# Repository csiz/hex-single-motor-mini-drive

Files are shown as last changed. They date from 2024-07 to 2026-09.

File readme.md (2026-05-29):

Hex Mini FOC driver
===================

Brushless motor driver for mini gear motors and servos. This driver focuses on fine force control
using field oriented control (FOC). The motor can be commanded to move to track position, 
velocity, and/or force. The driver will maintain the current wave exactly 90 degrees out
of phase to the EMF wave for maximum efficieny. Position is tracked via hall sensors, EMF
feedback and I2C rotary sensors.

Electrical ranges: 
- Maximum motor voltage: 28V
- Maximum current: 5A
- Minimum motor voltage: 6V
- Nominal I2C voltage: 3.3V

This project has 4 main components, for details look at the `readme.md` files in each directory:
* A brushless motor simulator and motor principles explainer; under `motor-sim`.
* The driver PCB schematic and manufacturing files; under `circuits`.
* Custom driver firmware with Kalman filter position tracking and FOC driving logic; under `driver-code`.
* Driver control and monitoring webapp; also under `motor-sim`, the page titled `motor-monitor.md`.

(TODO: this section needs updating to include the master circuit and master code and versioning and media and circuit libraries layout)

Screenshots
-----------

Motor monitor should look like this when connected to a motor: motor monitor screenshot

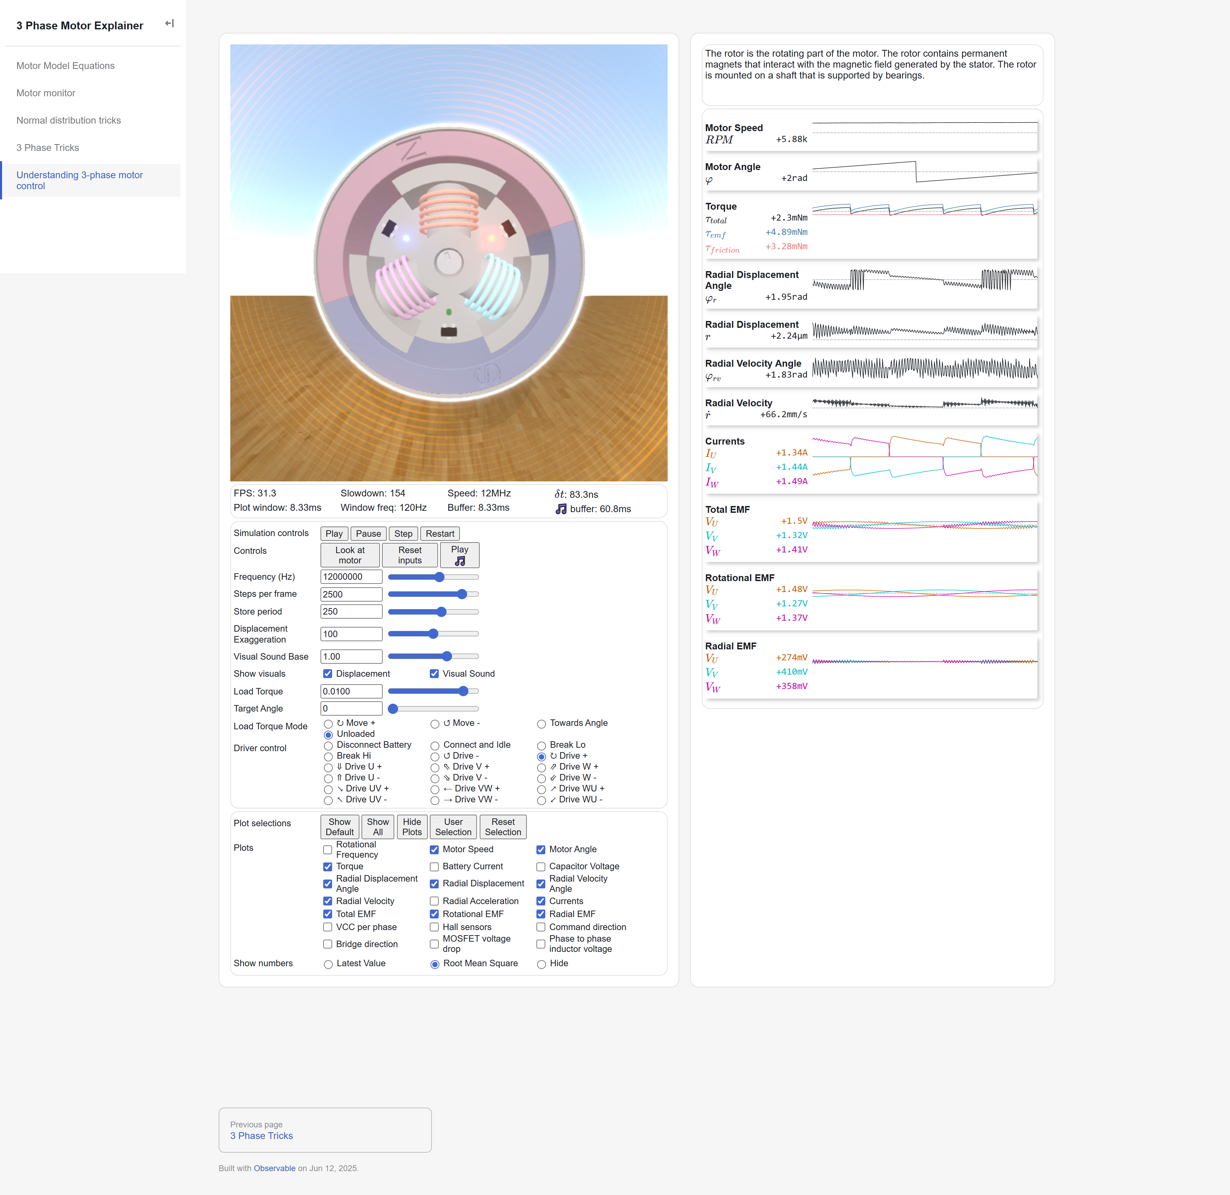
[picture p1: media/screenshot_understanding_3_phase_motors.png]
motor sim screenshot
The motor sim, with GPU rendered soundwaves should look like this: 

Circuit Dev Log
---------------

Lessons learnt for driver code v0.4
-----------------------------------

[ ] VREF must be independent of the reference to the amplifier; and actually well insulated. The v0.2 and v0.3 are too noisy because of this I suspect.
[ ] Let's go back to USB with 5V and separate VCC power connector! Also allows us to drop the on-board buck converter and save space. Bonus for easy to
control from a computer/phone with any USB cable.

Tasks for v0.3
--------------

[v] Maybe switch to a oscillation damping gate resistor of 3ohm. The AO4266E switching parameter uses 
Rgen = 3ohm, I think this is their recommended gate resistance. Switched to 4.7ohm, closest basic resistor.

[v] Aaaargh!!! BOOT0 pin needs a pulldown resistor on the STM32G4!
[x] VREF+ should be tied to VDDA... VREF+ now has the capacitance required and drives the amplifier refrence too.

[v] Think about connectors better. We should either drop or double down on USB-C. It would be very user friendly and the power delivery 
allows us to pick the 9-24V we need, but might be cumbersombe to control 24 devices. The SPI bus with slim connectors let's us keep it 
tight and in-house. Would we want a cheap single-sided board with USB-C and also a compact double sided assembly without USB at all.
... Let's go for double sided compact without USB, with the better stm32g4 with 5 opamps (so we can also ditch the opamp).
[v] USB-C footprint was correct with the cutouts. What we have now is incorrect!

[v] Need master circuit.
[v] Need flexi rotation I2C sensors.
[v] Via diameter was too small, should be at least 0.2/0.45

Need to implement in v0.2
-------------------------

Features of current version:
[v] Measure power line voltage.
[x] Re-pick voltage boost capacitor and resistor pair (using P FETS).
[v] Re-pick gate oscillation damping resistor for the inputs to the power MOSFET.
[v] Crystal oscilator and pick matching caps.
[v] Power regulator.
[v] USB-C connector maybe?
[v] Debugging connection with the trace line.
[v] 4 half bridge outputs
[v] 4 voltage inputs for the 4 outputs
[v] 1 voltage input for VCC
[v] 2 (preferably 4) current inputs from the 4 outputs; I chose 4.
[x] maybe 1 current input for total current. It would leave us with a floating ground which is iffy.
[v] SPI connection to main board. Not ~I2C~, it's too slow and consumes too much current. SPI will need
a chip select pin, but allows for parallel devices. SPI has hardware CRC calculation, seems useful.
[v] Spare I2C connection for the magnetic sensors.
[v] Status LED.

Lessons from previous version:
[x] Measure gate turn on characteristics of existing circuit...
[x] Maybe switch to a oscillation damping gate resistor of 3ohm. The AO4266E switching parameter uses 
Rgen = 3ohm, I think this is their recommended gate resistance.
[x] Definitely need to think about daisy chaining these, maybe use a signal buffer/transciever with an enable pin,
and/or mosfet switch for the chip power on. I2C to master board is probably the best and easiest way.
[v] Oopsies I flipped the sign of the V phase current measurement lines.
[x] The boost gate should maybe be connected to the driver side of the shunt resistor. At the moment we're measuring current used to charge the high gate.
[x] There's a summing option for the current measurments. Try outputing U, V, U+V, U+V+W using the 4th spare output.
[v] ! Think carefully about the shunt resistor placement, there's big interference going on if we measure during high side. Timing it around ground as
common mode voltage seems to fix it. Is that the only way to measure all current going through the motor coils?
[v] ! Measure voltage of the motor coils!
[x] There's a conflict between i2c and timer 3 channel 2. Choose a different GPIO for the red LED.
	I2C1 and TIM3_CH2 remapped
	Description
	When the following conditions are met:
	• I2C1 and TIM3 are clocked.
	• I/O port pin PB5 is configured as an alternate function output
	there is a conflict between the TIM3_CH2 signal and the I2C1 SMBA signal (even if SMBA is not used).
	In these cases the I/O port pin PB5 is set to 1 by default if the I/O alternate function output is selected and I2C1 is
	clocked. TIM3_CH2 cannot be used in output mode.
	Workaround
	To avoid this conflict, TIM3_CH2 can only be used in input mode.

[x] Double sided board. Not just yet.
[x] Drop voltage regulator and rely on master board for 3.3V; filter it though. We just needed to look for better 
components, there are cheap and small options that work well for us.
[x] Look for thinner IDC connector, and definitely SMD version for easier routing, use of space behind connector.
[v] Add voltage probes for the phase connectors so we can measure voltage both during driving and open connections.
We need to measure driving voltage to make sure our MOSFETS are turned on and giving us the voltage we command!
[v] Use Kelvin sense resistors (or pad hack) for the current measurement to avoid the unknown solder resistance.
https://www.analog.com/media/en/analog-dialogue/volume-46/number-2/articles/optimize-high-current-sensing-accuracy.pdf
[v] Don't drop the hall sensors, yet!
[v] The big problem with our measurements occurs when we switch from continuous 0 output from the low mosfet to mixed
output with the high mosfet. Any amount of mixed output seems to add an offset to our current measurement. Might be
worth putting the current sense only on the low mosfet branch.
[x] Choose a different mosfet driver to lower the minimum voltage under 5V. The undervoltage protection must be there
for a reason. Anyway, we chose 6V and up.
[v] Make it work with steppers... Neat!

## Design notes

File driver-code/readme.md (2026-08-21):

Driver Code
===========

This folder contains the driver code to be run on an STM32. Many files are autogenerated by the IDE, and
therefore there is a lot code. All the (non-generated) application code is under the folder `Code`, written
in C++.

Highlighted files:
```ini
.
├── Code
│   ├── Inc
│   │   ├── app_main.hpp         # Main application entry point.
│   │   ├── io.hpp               # Link between this STM32G4 and our inputs/outputs (like motor currents and PWM settings).
│   │   └── interrupts.hpp       # Interrupt handler definitions.
│   └── Src
│       ├── app_main.cpp         # After initialization the main app loop only handles comms and timekeeping.
│       │
│       └── interrupts.cpp       # Motor control logic! All motor control logic runs in the interrupt loop with
│                                # internal message passing to the main loop for data readouts and new commands.
│                                # 
│                                # We run a lot of code in the interrupts because motor control is the critical 
│                                # function of this driver chip. We do what we must because we can! The interrupt
│                                # is triggered when the ADC measures a set of phase currents. We must immediately
│                                # do math to transform the currents into the DQ0 frame and use those calculations
│                                # to set the motor PWM outputs for the upcoming cycle.
│
├── Core
│   └── Src
│       ├── main.c               # Invokes the app_main functions, otherwise it is autogenerated.
│       ├── stm32f1xx_it.c       # Invokes the interrupts, also autogenerated.
└── USB_DEVICE
    └── App
        └── usbd_cdc_if.c        # Invokes the USB send and receive functions, autogenerated.
#TODO: list all files mentioned in the section below.
```

New STM32 setup procedure
-------------------------

Install `STM32 Cube IDE / STM32 Cube MX`.

We need to configure CubeMX for our new board with the required peripherals:

From the `Project Manager` tab select `Project` and switch `Toolchain / IDE` to `CMake`.

* System Core:
    + NVIC: Ensure the `ADC1 and ADC2 global interrupt` is activated.
    + RCC: Switch High Speed Clock to `Crystal/Ceramic Resonator`.
    + SYS: Enable `Serial Wire` for debug and switch `Timebase Source` to any other time; we need to leave `SysTick` free in case we enable RTOS.
    Enable the internal reference and set it to 2.9V.
* Timers:
    + TIM1: Setup 4 channels with positive and negative PWM (8 pins). 
    Set `Counter Mode` to `Center Aligned mode1`. 
    Set an extra channel as `PWM Generation No Output` for timing the analog reads.
    Enable `auto-reload preload`.
    Set `Trigger Event Selection TRGO2` to `Output Compare (OC5REF)` so we can use it to time the ADC reads.
    + TIM2 & TIM4: Setup 3 PWM channels for the status LED; set `Channel Polarity` to `Low`. Set `Counter Period` to `256`.
    + TIM3: Set `Combined Channels` to `XOR ON / Hall Sensor Mode`. In `GPIO Settings` tab of the configuration, 
    set all 3 channels to `Pull-up` to high level and `Alternate Function Open Drain` (ps scroll down to see the options).
* Connectivity:
    + I2C2 & I2C3: Enable on default settings.
    + SPI2: Enable as `Full-Duplex Slave` with `Hardware NSS Input Signal`. I set `Frame Format` to `Motorola` and `Data Size` to `8 Bits`, but not sure of right settings yet.
    ! We need to also enable the DMA buffers.
    + USART3: Enable `Asynchornous` mode.
    + USB: Enable it on the `Internal Phy`.
    ! Also enable it under "Middleware" as `USB_DEVICE` and select `Communication Device Class (Virtual Port Com)`.
* Analog ADC1 & ADC2:
    + Set `ADCs_Common_Settings` to `Independent Mode`! Yes, this one, the other dual options
    seem to work exactly once for ADC2, don't understand why... The ALTERTRIG option triggers one
    ADC then the other but not both at the same time. We are left with independent mode, however
    we trigger both ADCs from the same timer event and so they are still synchronized.
    + Set `External Trigger Source` to `Timer 1 Trigger Out event 2`.
    + Disable call HAL handler for ADC 1 & 2.
    + Setup the adc channels according to `io.hpp` needs.

Open `hex-mini-driver.ioc` and use the `Generate Code` tool from the STM32 Cube IDE.

After generating the CubeMX configuration code we need to make the following changes:
    1. Make sure it compiles... The `CMakeFiles` are generated once and then left to the user to edit, we must include all used libraries. Since Cube MX doesn't update the make files it won't add libraries that we enable after the first time we autogenerate code.
    2. Copy `USB_DEVICE/App/usbd_cdc_if.c`. It contains the circular buffer implementation for USB data. It must remain implemented here because Cube MX autogenerates the functions as private to this file.
    3. In `Core/Src/main.c` we must add the includes:
        `
        #include "app_main.hpp"
        #include "error_handler.hpp"
        `
    then insert our initialization and infinite loop at the end of the Cube MX initialization that we configured in the Cube IDE:
        `
          /* Infinite loop */
          /* USER CODE BEGIN WHILE */
          app_init();
          while (1) {
            /* USER CODE END WHILE */
            /* USER CODE BEGIN 3 */
            app_tick();
          }
          /* USER CODE END 3 */
        `
    and finally, use our C++ error handler:
        `
        void Error_Handler(void)
        {
          /* USER CODE BEGIN Error_Handler_Debug */
          /* User can add his own implementation to report the HAL error return state */
          error();
          /* USER CODE END Error_Handler_Debug */
        }
        `
    5. In `Core/USB_Device/App/usbd_cdc_if.c` we must include our C++ USB handlers:
        `
        /* USER CODE BEGIN INCLUDE */
        #include "main.h"
        #include "usb_com.hpp"
        /* USER CODE END INCLUDE */
        `
    and the handlers:
        `
        static int8_t CDC_Init_FS(void)
        {
        /* USER CODE BEGIN 3 */
        usb_init();
        return (USBD_OK);
        /* USER CODE END 3 */
        }
        `
        `
        static int8_t CDC_DeInit_FS(void)
        {
        /* USER CODE BEGIN 4 */
        usb_deinit();
        return (USBD_OK);
        /* USER CODE END 4 */
        }
        `
        `
        static int8_t CDC_Receive_FS(uint8_t* Buf, uint32_t *Len)
        {
        /* USER CODE BEGIN 6 */
        usb_received(*Len);
        return (USBD_OK);
        /* USER CODE END 6 */
        }
        `
    That's it for the autogenerated code mixing; our code should now all be in `Code`.
    6. Copy the `Code` folder over.
    7. Add our sources and include paths to `CMakeLists.txt`:
        `
        # All cpp sources under the "Code/Src" directory
        file(GLOB_RECURSE USER_SOURCES "Code/Src/*.c" "Code/Src/*.cpp")
        # Add sources to executable
        target_sources(${CMAKE_PROJECT_NAME} PRIVATE
            ${USER_SOURCES}
        )
        # Add include paths
        target_include_directories(${CMAKE_PROJECT_NAME} PRIVATE
            # Add user defined include paths
            "Code/Inc"
            "../Interface/dist/"
        )
        `
    8. Update `cmake/gcc-arm-none-eabi.cmake` with our C++ build flags:
        `
        set(CMAKE_C_FLAGS "${CMAKE_C_FLAGS} -fwrapv -Wall -Wextra -Wpedantic -fdata-sections -ffunction-sections -Wno-unused-parameter -Wno-missing-field-initializers")
        set(CMAKE_CXX_FLAGS "${CMAKE_C_FLAGS} -std=gnu++23 -fno-rtti -fno-exceptions -fno-threadsafe-statics -Wno-register -Wno-narrowing -Werror=switch")
        `
    9. Edit the linker script, a file that looks like `stm32.*_flash.ld`, we need to reserve a small section for user data.
    Edit the `MEMORY` section according to the target chip, must look like:
        `
        /* Specify the memory areas */
        MEMORY
        {
        RAM (xrw)      : ORIGIN = 0x20000000, LENGTH = 32K
        FLASH (rx)      : ORIGIN = 0x8000000, LENGTH = 120K
        DATA (xrw)      : ORIGIN = 0x801E000, LENGTH = 8K
        }
        `
    We must add the name for our section inside `SECTIONS`:
        `
          /* Reserve the last pages of flash for user data (calibration). */
          .user_data (NOLOAD) : {
            . = ALIGN(4);
            KEEP(*(.user_data))
            . = ALIGN(4);
          } > DATA
        `
    Fix the linker warning by adding `(READONLY)` to the following lines, also inside `SECTIONS`:
        `
          .preinit_array (READONLY) :
          .init_array (READONLY) :
          .fini_array (READONLY) :
        `
    10. Attach the GPIO outputs to the proper routines (TODO: need a file where the pinout is defined all together).
    11. To properly setup VSCode we must copy over these files:
        * `.vscode/c_cpp_properties.json`
        * `.vscode/tasks.json`
        * `.vscode/launch.json`

TODO: install procedure
TODO: compile procedure
TODO: upload procedure
TODO: links to control interface
TODO: update the file descriptions above

TODO: ... fix error handler, must stop motor disable IRQ and display LED.

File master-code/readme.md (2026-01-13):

Hex mini driver master controller
=================================

This is the main controller code for the Hex single motor mini drive system. It is designed to run on an ESP32-S3 microcontroller and provides the necessary functionality to control 24V servos, communicate via CAN bus and wi-fi.

Settings up dev environment
---------------------------
* Need to install [PlatformIO](https://platformio.org/install/ide?install=vscode) extension for VSCode.
* Might have delete the pio libraries if switching framework versions.
* Install [ESP32-S3 toolchain](https://docs.platformio.org/en/latest/platforms/espressif32.html#installation) if not done automatically by PlatformIO.
* Need to install the [ESP32-S3 JTAG drivers](https://docs.platformio.org/en/latest/boards/espressif32/esp32-s3-devkitc-1.html#debugging) for uploading and debugging over JTAG.

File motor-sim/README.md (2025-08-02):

Motor Simulator & Control
-------------------------

The motor control page and an explanatory simulator are built using the [Observable Framework](https://observablehq.com/framework). 
To start the local preview server, run:

```
npm run dev
```

Then visit <http://localhost:3000> to preview your app.

Webapp structure
----------------

The main entry points for the motor simulator and driver controller are listed below:

```ini
.
├─ src
│  ├─ components
│  │  ├─ motor_controller.js   # Code to connect to the motor (will be extracted into a separate lib eventually).
│  │  ├─ motor_interface       # Motor driver API. This is the USB interface, which will be kept consistent with I2C, SPI and CAN interfaces.
│  │  └─ simulations.js        # Code driving the motor simulator.
│  ├─ data
│  │  └─ motor_model.3mf       # An example motor 3D model.
│  │  
│  ├─ index.md                 # Homepage!
│  ├─ motor_monitor.md         # Motor control page! (Use this page as reference for connecting to the motor programmatically.)
│  ├─ motor_model.md           # Physics equation describing the 3 phase motor electrical relations.
│  ├─ normal_dist_tricks.md    # Illustration for combining Gaussian distributions and for the Kalman filter position updates.
│  └─ three_phase_tricks.md    # Tricks and trigonometric tables to use for driving the motor with the maximum voltage range.
│
├─ .gitignore
├─ observablehq.config.js      # The app config file.
├─ package.json
└─ README.md
```

For reference, the typical Framework project looks like this:

- `src`: This is the “source root” — where your source files live. Pages go here. Each page is a Markdown file. Observable Framework uses [file-based routing](https://observablehq.com/framework/routing), which means that the name of the file controls where the page is served. You can create as many pages as you like. Use folders to organize your pages.
- `src/index.md`: This is the home page for your app. You can have as many additional pages as you’d like, but you should always have a home page, too.
- `src/data`: You can put [data loaders](https://observablehq.com/framework/loaders) or static data files anywhere in your source root, but we recommend putting them here.
- `src/components`: You can put shared [JavaScript modules](https://observablehq.com/framework/javascript/imports) anywhere in your source root, but we recommend putting them here. This helps you pull code out of Markdown files and into JavaScript modules, making it easier to reuse code across pages, write tests and run linters, and even share code with vanilla web applications.
- `observablehq.config.js`: This is the [app configuration](https://observablehq.com/framework/config) file, such as the pages and sections in the sidebar navigation, and the app’s title.

Command reference
-----------------

| Command | Description |
| --- | --- |
| `npm install` | Install or reinstall dependencies |
| `npm run dev` | Start local preview server |
| `npm run build` | Build your static site, generating `./dist` |
| `npm run deploy` | Deploy your app to Observable |
| `npm run clean` | Clear the local data loader cache |
| `npm run observable` | Run commands like `observable help` |

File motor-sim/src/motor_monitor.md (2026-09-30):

---
title: Motor monitor
---

<!-- This is the monitor page for the motor controller, the code here is used to showcase
the typical usage of the javascript motor interface in order to control the motor.

Note that we are using the Observable Framework (https://observablehq.com/framework/) for
reactivity. The code blocks encoded by ```js ... ``` are reactive and will automatically
update when the underlying data changes. Most top level variables are effectively async 
iterators and the framework allows us to work with them as if they are simple variables,
simplifying the code. It also allows for imports and misc functions to be written last.

The code is organized as follow:

1. The HTML layout is specified at the top.

2. The first code block contains the connecting logic for the motor controller and handles
the resulting data stream and status updates. We can connect to multiple motors at a time.

3. The second block defines the interactive buttons and inputs for controlling the motor.

4. The following blocks setup the plotting and motor feedback. The UI configuration is
long and verbose, but intentionally kept on this page for completeness. You may use ctrl+F
to search for any term visible on the application page. Every bit of text from the motor
monitor page can be found written somewhere in this file.

5. Finally we have on device unit tests, imports, and other utility code.

-->

<main class="hero">

Motor Commands
--------------
<div class="card tight">
<div>${connect_buttons}</div>
<div>${connection_status}</div>
<div>${opened_ports_radio}</div>
<div>${data_request_buttons}</div>
<div>
  <span>${command_options_input}</span>
  <span>${command_snapshot_delay_slider}</span>
</div>
<div>${stop_buttons}</div>
<div>${test_buttons}</div>
<div>
  <span>${simple_drive_buttons}</span>
  <span>${command_timeout_slider}</span>
  <span>${command_pwm_slider}</span>
</div>
<div>
  <span>${advanced_drive_buttons}</span>
  <span>${command_angle_slider}</span>
  <span>${command_angular_speed_slider}</span>
  <span>${command_torque_current_slider}</span>
  <span>${command_power_slider}</span>
</div>
<div>
  <span>${seek_drive_buttons}</span>
  <span>${command_seek_rotation_slider}</span>
  <span>${shared_seek_buttons}</span>
</div>
</div>

Motor Driving Data
------------------
<div class="card tight">
<p>Controls for the plotting time window:</p>
  <span>${time_period_input}</span>
  <span>${time_offset_input}</span>
  <span>${plot_curve_input}</span>
  <span>${timeline_position_input}</span>
</div>
<div class="card tight">${plot_power}</div>
<div class="card tight">${plot_runtime_stats}</div>
<div class="card tight">${plot_cycle_loop_stats}</div>
<div class="card tight">${plot_electric_position}</div>
<div class="card tight">${plot_electric_offsets}</div>
<div class="card tight">${plot_speed}</div>
<div class="card tight">${plot_measured_voltage}</div>
<div class="card tight">${plot_measured_temperature}</div>
<div class="card tight">${plot_measured_current}</div>
<div class="card tight">${plot_voltages}</div>
<div class="card tight">${plot_inferred_voltages}</div>
<div class="card tight">${plot_dq0_currents}</div>
<div class="card tight">${plot_dq0_voltages}</div>
<div class="card tight">${plot_pwm_settings}</div>
<div class="card tight">${plot_readout_flags}</div>
<div class="card tight">${plot_motor_values}</div>

Current Calibration Procedures
------------------------------

<div class="card tight">
  <div>${current_calibration_buttons}</div>
  <p>Active electrical phase properties:</p>
  <pre>${active_current_calibration_table}</pre>
  <div>${Object.values(current_calibration_input)}</div>
</div>
<div class="card tight">
  <div>${current_calibration_run_buttons}</div>
  <div>${current_calibration_pwm_slider}</div>
  <div>${current_calibration_test_speed_slider}</div>
  <div>${current_calibration_test_duration_slider}</div>
  <div>${current_calibration_angle_slider}</div>
  <div>${current_calibration_checkboxes}</div>
  <h3>Current Calibration Results</h3>
  <div>${current_calibration_optimization_iteration_input}</div>
  <div>
    <p>Electrical phase properties at displayed iteration:</p>
    <pre>${current_calibration_iteration_table}</pre>
    <div>${current_calibration_optimizing_plot}</div>
    <div>${current_calibration_angles_plot}</div>
    <div>${current_calibration_angles_scatter}</div>
    <div>${current_calibration_optimizing_gradients_plot}</div>
  </div>

</div>

Motor Control Parameters
------------------------

<div class="card tight">
  <div>${control_parameters_buttons}</div>
  <h3>Active Control Parameters</h3>
  <p>These are the currently active parameters for the motor controller.</p>
  <pre>${active_control_parameters_table}</pre>
</div>

<div class="card tight">
  <h3>Control Parameters</h3>
  <div>${Object.values(control_parameters_input)}</div>
</div>

Flash Data Storage
------------------

<div class="card tight">
  <p>Commit the uploaded calibration data to flash memory.</p>
  <div>${flash_buttons}</div>
  <pre>${flash_status}</pre>
</div>

Unit Tests
----------

<div class="card tight">
  <p>Run the unit tests for the motor controller. These tests focus on internal math functions.</p>
  <div>${unit_test_buttons}</div>
  <div>${unit_test_results}</div>
</div>

</main>

```js
// USB Connection and Data
// -----------------------

// Active data to be displayed on the main plots.
let data = Mutable([]);

// Active motor controller (can be null or selected from multiple motor connections).
let motor_controller = Mutable(null);

// Currently active USB port.
let active_port = Mutable(null);

// Opened USB ports, and respectively the motor controllers and data associated with each.
let opened_ports = Mutable(new Map());

// Prominently displayed status for the motor monitor page.
let connection_status = Mutable(html`<pre>Not connected.</pre>`);

// Data management
// ---------------

function set_readout_series(new_data, motor_uri){
  if (motor_uri === active_port.value) data.value = new_data;

  opened_ports.value.get(motor_uri).data = new_data;
}

function update_readout_series(readout, motor_uri){
  // Reset the data when the controller detects a new readout series and resets the index to 0.
  const first_readout = (readout.readout_index === 0);

  const previous_data = opened_ports.value.get(motor_uri)?.data ?? [];

  const new_data = first_readout ? [readout] : capped_push(previous_data, readout);

  if (motor_uri === active_port.value) data.value = new_data;

  opened_ports.value.get(motor_uri).data = new_data;
};

function set_status(status, motor_uri){
  if (!motor_controller.value || motor_uri === active_port.value) connection_status.value = status;

  opened_ports.value.get(motor_uri).status = status;
}

function set_error(error, motor_uri){
  if (!motor_controller.value || motor_uri === active_port.value) {
    connection_status.value = displayable_connection_error(error);
  }

  opened_ports.value.get(motor_uri).error = error;
}

function set_motor_controller(controller, motor_uri){
  opened_ports.value.get(motor_uri).motor_controller = controller;

  // Self assign to update the `Mutable`.
  opened_ports.value = opened_ports.value;
}

function switch_to_port(motor_uri){
  const port_state = opened_ports.value.get(motor_uri);

  if (!port_state) return false;

  active_port.value = motor_uri;

  motor_controller.value = port_state.motor_controller;
  connection_status.value = port_state.error ? displayable_connection_error(port_state.error) : port_state.status;
  data.value = port_state.data;

  return true;
}

// Initialize Motor Driver via USB or WiFi
// ---------------------------------------

const default_connect_options = {force_ws: false};

async function connect_motor_controller(options = {}) {
  const {force_ws} = {...default_connect_options, ...options};
  
  try {
    const port_index = force_ws ? null : await prompt_com_port_get_index();

    const motor_uri = (port_index === null || force_ws) ? default_ws_uri : `usb:${port_index}`;

    // Switch to the existing motor controller if this port is already opened and initialized.
    if (switch_to_port(motor_uri)) return;

    // Append this port to the opened ports list so we can capture it's errors too.
    opened_ports.value = opened_ports.value.set(motor_uri, {
      motor_uri,
      motor_controller: null,
      data: [],
      status: html`<pre>Opening USB com port.</pre>`,
      error: undefined,
    });

    const motor_controller = new MotorController({
      motor_uri,
      onstatus: (status) => {
        set_status(html`<pre>Connected; ${format_data_rate(status)}.</pre>`, motor_uri);
      },
      onmessage: (readout) => {
        update_readout_series(readout, motor_uri);
      },
      onready: (motor_controller) => {
        set_status(html`<pre>Connected, waiting for your commands.</pre>`, motor_uri);
        set_motor_controller(motor_controller, motor_uri);
        switch_to_port(motor_uri);
      },
      onerror: (error) => {
        set_error(error, motor_uri);
      },
      onclose: () => {
        opened_ports.value.delete(motor_uri);
        // Self assign to update the `Mutable`.
        opened_ports.value = opened_ports.value;
      },
    });

    // Switch the display to the newly opening port.
    switch_to_port(motor_uri);

  } catch (error) {
    connection_status.value = displayable_connection_error(error);
  }
}

async function disconnect_motor_controller(show_status = true){
  if (motor_controller.value) {
    console.info("Disconnecting motor controller; forgetting port.");
    await motor_controller.value.forget();
    motor_controller.value = null;
    if (show_status) {
      connection_status.value = html`<pre style="color: orange">Disconnected!</pre>`;
    }
  }
}

```

```js

// Setup Buttons and Inputs
// ------------------------

// Automatically connect the motor driver if we have permissions from previous session.
connect_motor_controller({force_ws: false});

// Disconnect when the notebook is reloaded.
invalidation.then(disconnect_motor_controller);

// Buttons to manually connect, disconnect and manage multiple motor connections.
const connect_buttons = Inputs.button(
  [
    ["Connect USB", () => connect_motor_controller({force_ws: false})],
    ["Connect WiFi", () => connect_motor_controller({force_ws: true})],
    ["Disconnect", disconnect_motor_controller],
    // ["Reset data & inputs", () => (clear_stored_data(), location.reload())],
  ],
  {label: "Connect to COM"},
);
d3.select(connect_buttons).selectAll("button").style("height", "3em");

// The following variables are pairs of input html elements and their corresponding input value observers.

const command_options_input = Inputs.checkbox(
  ["Take snapshot after command"],
  {
    value: [],
    label: "Command options:",
  },
);
d3.select(command_options_input).select("div").style("width", "100%");
d3.select(command_options_input).select("div label").style("width", "100em");
const command_snapshot = transformed_input_value(command_options_input, (options) => options.includes("Take snapshot after command"));

// Delay the command snapshot by a set millisecond duration from the start of the main command.
const command_snapshot_delay_slider = inputs_wide_range([0, 1000], {value: 500, step: 1, label: "Snapshot delay (ms):"});
const command_snapshot_delay = Generators.input(command_snapshot_delay_slider);

// Slider to choose the command specific PWM setting.
const command_pwm_slider = inputs_wide_range([0, PWM_BASE], {value: PWM_BASE * 0.05, step: 1, label: "Command value:"});
const command_pwm = transformed_input_value(command_pwm_slider, (value) => Math.floor(value));

// Timeout duration for each command. For safety, the motor runs each drive command for a short period until commanded again.
const command_timeout_slider = inputs_wide_range([0, max_timeout*millis_per_cycle], {value: 510, step: 1, label: "Command timeout (ms):"});
const command_timeout = transformed_input_value(command_timeout_slider, (millis) => Math.floor(millis * cycles_per_millisecond));

// Choose the angular speed target for certain commands.
const command_angular_speed_slider = inputs_wide_range(
  [
    0.0,
    speed_units_to_rotations_per_millisecond(max_angular_speed)
  ], 
  {value: 0.20, step: 0.01, label: "Angular speed value (rotations/ms)"});
const command_angular_speed = transformed_input_value(command_angular_speed_slider, rotations_per_millisecond_to_speed_units);

// Choose the target angle for certain commands.
const command_angle_slider = inputs_wide_range([-Math.PI, Math.PI], {value: 0, step: 0.01, label: "Command angle (radians):"});
const command_angle = transformed_input_value(command_angle_slider, radians_to_angle_units);

// Choose the torque target for torque driving modes.
const command_torque_current_slider = inputs_wide_range([0, max_drive_current], {value: 0.750, step: 0.010, label: "Command torque (Amps):"});
const command_torque_current = transformed_input_value(command_torque_current_slider, (amps) => amps * CURRENT_UNITS_PER_AMP);

// Choose the power target for power driving modes.
const command_power_slider = inputs_wide_range([0, max_drive_power], {value: 1.500, step: 0.010, label: "Command power (Watts):"});
const command_power = Generators.input(command_power_slider);

// Choose the position for target seeking.
const command_seek_rotation_slider = inputs_wide_range([-1024, +1024], {value: 0, step: 1, label: "Seek angle (rotations):"});
const command_seek_rotation = Generators.input(command_seek_rotation_slider);

// We must start a new code cell for the variables above to become observables.
```
```js

const opened_ports_radio = Inputs.radio(
  opened_ports.keys(),
  {
    label: "Opened ports", 
    value: active_port,
    format: (port, i) => {
      return html`<pre>Motor ${i}</pre>`;
    },
  }
);
opened_ports_radio.addEventListener("input", function(){
  const port = opened_ports_radio.value;
  if (port) switch_to_port(port);
});

// Control functions
// -----------------

// Send a command, automatically adding the shared timeout parameter.
async function send_command(message){
  if (!motor_controller) return;

  if (typeof message === "object") {
    message = {
      ...message,
      timeout: command_timeout,
    };
  }

  await motor_controller.send_command(message);
}

// Take a snapshot of continuously recorded readouts from the motor controller.
async function take_readout_snapshot(command_options = {}){
  if (!motor_controller) return;

  // Remember the current controller and port before we await.
  const controller = motor_controller;
  const port = active_port;

  const reply_data = await controller.send_command_and_await_reply({
    message: MessageCode.GET_READOUTS_SNAPSHOT,
    expected_code: MessageCode.READOUT,
    expected_messages: HISTORY_SIZE,
    ...command_options,
  });

  set_readout_series(reply_data, port);
}

// Run the test driving commands. The test commands can send a snapshot taken
// during the test procedure if requested (using the timeout parameter as a flag.)
async function test_command(message_code){
  const message = {
    message_code, 
    pwm_value: command_pwm, 
    test_speed: command_angular_speed,
    test_duration: command_timeout,
    take_snapshot: command_snapshot ? 1 : 0,
  };

  if (command_snapshot){
    await take_readout_snapshot({
      message,
      expected_code: MessageCode.READOUT,
      expected_messages: HISTORY_SIZE,
    });
  } else {
    await send_command(message);
  }
}

// Take a snapshot after a user specified delay using a slider in the UI.
const delayed_readout_snapshot = _.debounce(take_readout_snapshot, command_snapshot_delay);

// Take a snapshot if the snapshot option is checked in the UI.
async function snapshot_if_checked(message){
  await send_command(message);

  if (command_snapshot) delayed_readout_snapshot();
}

async function stream_all_motors(){
  for (const {motor_controller} of opened_ports.values()) {
    if (!motor_controller) continue;
    motor_controller.reset_history();
    await motor_controller.send_command({message_code: MessageCode.STREAM_FULL_READOUTS, stream_state: 1});
  }
}

let command_interval = null;
const command_loop_period = 1;

function stop_command_loop(){
  if(command_interval) {
    clearInterval(command_interval);
    command_interval = null;
  }
}

function start_command_loop(loop_function){
  stop_command_loop();
  stream_all_motors();
  command_interval = setInterval(loop_function, command_loop_period);
}

// All the buttons
// ---------------

const data_request_buttons = Inputs.button(
  [
    ["Uninterrupted snapshot", async function(){ 
      await take_readout_snapshot(); 
    }],
    ["Stream motor data", async function(){
      motor_controller.reset_history();
      await send_command({message_code: MessageCode.STREAM_FULL_READOUTS, stream_state: 1});
    }],
    ["STOP stream", async function(){
      stop_command_loop();

      await send_command({message_code: MessageCode.STREAM_FULL_READOUTS, stream_state: 0});
    }],
    ["Stream all motors", stream_all_motors],
    ["Stop all motors", async function(){
      stop_command_loop();

      for (const {motor_controller} of opened_ports.values()) {
        if (!motor_controller) continue;
        await motor_controller.send_command({message_code: MessageCode.STREAM_FULL_READOUTS, stream_state: 0});
      }
    }],
  ],
  {label: "Read data"},
);
d3.select(data_request_buttons).selectAll("button").style("height", "4em");

const test_buttons_to_code = [
  ["Test all permutation", MessageCode.SET_STATE_TEST_ALL_PERMUTATIONS],
  ["Test ground short", MessageCode.SET_STATE_TEST_GROUND_SHORT],
  ["Test positive short", MessageCode.SET_STATE_TEST_POSITIVE_SHORT],
  // ["Test U increasing", MessageCode.SET_STATE_TEST_U_INCREASING],
  // ["Test U decreasing", MessageCode.SET_STATE_TEST_U_DECREASING],
  // ["Test V increasing", MessageCode.SET_STATE_TEST_V_INCREASING],
  // ["Test V decreasing", MessageCode.SET_STATE_TEST_V_DECREASING],
  // ["Test W increasing", MessageCode.SET_STATE_TEST_W_INCREASING],
  // ["Test W decreasing", MessageCode.SET_STATE_TEST_W_DECREASING],
  ["Resistance calibration", MessageCode.SET_STATE_RESISTANCE_CALIBRATION],
  ["Inductance calibration", MessageCode.SET_STATE_INDUCTANCE_CALIBRATION],
  ["Rotating chirp calibration", MessageCode.SET_STATE_ROTATING_CALIBRATION_CHIRP],
  ["Fixed chirp calibration", MessageCode.SET_STATE_FIXED_CALIBRATION_CHIRP],
  ["HFI Saliency Pulses", MessageCode.SET_STATE_HFI_SALIENCY_PULSES],
];

const test_buttons = Inputs.button(
  test_buttons_to_code.map(([label, code]) => [label, () => test_command(code)]),
  {label: "Test sequence"},
);
d3.select(test_buttons).selectAll("button").style("height", "4em");

const stop_buttons = Inputs.button(
  [
    ["Stop / Brake", async function(){
      stop_command_loop();

      await snapshot_if_checked({message_code: MessageCode.SET_STATE_OFF});
    }],
    ["Freewheel", async function(){
      stop_command_loop();

      await snapshot_if_checked({message_code: MessageCode.SET_STATE_FREEWHEEL});
    }],
    ["Stop all motors", async function(){
      stop_command_loop();

      for (const {motor_controller} of opened_ports.values()) {
        if (!motor_controller) continue;
        await motor_controller.send_command({message_code: MessageCode.SET_STATE_OFF});
      }
    }]
  ],
  {label: "Stop Commands"},
);

d3.select(stop_buttons)
  .style("margin-top", "1em")
  .style("margin-bottom", "1em")
  .selectAll("button")
    .style("height", "5em")
    .style("font-weight", "bold")
    .style("color", "darkred");

const simple_drive_buttons = Inputs.button(
  [
    ["Drive 6S +", async function(){
      await snapshot_if_checked({message_code: MessageCode.SET_STATE_DRIVE_6_SECTOR, pwm_value: +command_pwm});
    }],
    ["Drive 6S -", async function(){
      await snapshot_if_checked({message_code: MessageCode.SET_STATE_DRIVE_6_SECTOR, pwm_value: -command_pwm});
    }],
    // ["Hold U positive", async function(){
    //   await snapshot_if_checked({message_code: MessageCode.SET_STATE_HOLD_U_POSITIVE, pwm_value: command_pwm});
    // }],
    // ["Hold V positive", async function(){
    //   await snapshot_if_checked({message_code: MessageCode.SET_STATE_HOLD_V_POSITIVE, pwm_value: command_pwm});
    // }],
    // ["Hold W positive", async function(){
    //   await snapshot_if_checked({message_code: MessageCode.SET_STATE_HOLD_W_POSITIVE, pwm_value: command_pwm});
    // }],
    // ["Hold U negative", async function(){
    //   await snapshot_if_checked({message_code: MessageCode.SET_STATE_HOLD_U_NEGATIVE, pwm_value: command_pwm});
    // }],
    // ["Hold V negative", async function(){
    //   await snapshot_if_checked({message_code: MessageCode.SET_STATE_HOLD_V_NEGATIVE, pwm_value: command_pwm});
    // }],
    // ["Hold W negative", async function(){
    //   await snapshot_if_checked({message_code: MessageCode.SET_STATE_HOLD_W_NEGATIVE, pwm_value: command_pwm});
    // }],
  ],
  {label: "Simple drive commands"},
);
d3.select(simple_drive_buttons).selectAll("button").style("height", "4em");

const advanced_drive_buttons = Inputs.button(
  [
    ["Set Angle", async function(){
      await snapshot_if_checked({
        message_code: MessageCode.SET_ANGLE, 
        angle: command_angle,
      });
    }],
    ["Drive periodic +", async function(){
      await snapshot_if_checked({
        message_code: MessageCode.SET_STATE_DRIVE_PERIODIC,
        pwm_value: command_pwm, 
        angular_speed: +command_angular_speed, 
        angle: command_angle,
      });
    }],
    ["Drive periodic -", async function(){
      await snapshot_if_checked({
        message_code: MessageCode.SET_STATE_DRIVE_PERIODIC,
        pwm_value: command_pwm, 
        angular_speed: -command_angular_speed, 
        angle: command_angle,
      });
    }],
    ["Drive smooth +", async function(){
      await snapshot_if_checked({
        message_code: MessageCode.SET_STATE_DRIVE_SMOOTH,
        pwm_value: +command_pwm
      });
    }],
    ["Drive smooth -", async function(){
      await snapshot_if_checked({
        message_code: MessageCode.SET_STATE_DRIVE_SMOOTH,
        pwm_value: -command_pwm
      });
    }],
    ["Drive torque +", async function(){
      await snapshot_if_checked({
        message_code: MessageCode.SET_STATE_DRIVE_TORQUE,
        target_current: +command_torque_current
      });
    }],
    ["Drive torque -", async function(){
      await snapshot_if_checked({
        message_code: MessageCode.SET_STATE_DRIVE_TORQUE,
        target_current: -command_torque_current
      });
    }],
    ["Drive power +", async function(){
      await snapshot_if_checked({
        message_code: MessageCode.SET_STATE_DRIVE_BATTERY_POWER,
        target_power: +command_power,
      });
    }],
    ["Drive power -", async function(){
      await snapshot_if_checked({
        message_code: MessageCode.SET_STATE_DRIVE_BATTERY_POWER,
        target_power: -command_power,
      });
    }],
    ["Drive speed +", async function(){
      await snapshot_if_checked({
        message_code: MessageCode.SET_STATE_DRIVE_SPEED,
        target_speed: +command_angular_speed
      });
    }],
    ["Drive speed -", async function(){
      await snapshot_if_checked({
        message_code: MessageCode.SET_STATE_DRIVE_SPEED,
        target_speed: -command_angular_speed
      });
    }],
    ["Drive torque speed +", async function(){
      await snapshot_if_checked({
        message_code: MessageCode.SET_STATE_DRIVE_TORQUE_SPEED,
        target_speed: +command_angular_speed,
        target_current: +command_torque_current,
      });
    }],
    ["Drive torque speed -", async function(){
      await snapshot_if_checked({
        message_code: MessageCode.SET_STATE_DRIVE_TORQUE_SPEED,
        target_speed: -command_angular_speed,
        target_current: -command_torque_current,
      });
    }],
  ],
  {label: "Advanced drive commands"},
);
d3.select(advanced_drive_buttons).selectAll("button").style("height", "4em");

const seek_drive_buttons = Inputs.button(
  [
    ["Set Rotations", async function(){
      await snapshot_if_checked({
        message_code: MessageCode.SET_ROTATIONS, 
        rotations: command_seek_rotation,
      });
    }],
    ["Seek angle", async function(){
      await snapshot_if_checked({
        message_code: MessageCode.SET_STATE_SEEK_ANGLE,
        target_rotation: command_seek_rotation, 
        target_angle: command_angle,
        target_speed: command_angular_speed,
        target_current: command_torque_current,
      });
    }],
    ["Go to zero", async function(){
      await snapshot_if_checked({
        message_code: MessageCode.SET_STATE_SEEK_ANGLE,
        target_rotation: 0, 
        target_angle: 0,
        target_speed: command_angular_speed,
        target_current: command_torque_current,
      });
    }],
  ],
  {label: "Seek to target position"},
);
d3.select(seek_drive_buttons).selectAll("button").style("height", "4em");

const shared_prediction_millis = 100;

function get_average_position(){
  const valid_ports = Array.from(opened_ports.values()).filter(({motor_controller, data}) => {
    return motor_controller && data?.length >= 1;
  });

  if (valid_ports.length < 2) return;

  return Math.round(d3.mean(valid_ports, ({data}) => {
    const last_readout = _.last(data);
    return last_readout.rotations + last_readout.angular_speed / 360 * shared_prediction_millis;
  }));
}

const shared_seek_buttons = Inputs.button(
  [
    ["Virtual spring", function(){

      start_command_loop(() => {
        const target_position = get_average_position();
        if (!_.isFinite(target_position)) return;

        command_seek_rotation_slider.value = target_position;

        for (const {motor_controller: controller} of opened_ports.values()) {
          if (!controller) continue;

          controller.send_command({
            message_code: MessageCode.SET_STATE_SEEK_ANGLE_WITH_TORQUE,
            timeout: command_timeout,
            target_angle: command_angle,
            max_drive_current: command_torque_current,
            target_rotation: target_position,
          });
        }
      });

    }],

    ["Follow selected motor", function(){

      start_command_loop(() => {
        // Can't use the `data` generator because it updates too fast and stops our buttons from working.
        const target_position = _.last(Array.from(opened_ports.values()).filter(({motor_controller: controller}) => {
          return motor_controller === controller;
        })[0]?.data)?.rotations;

        if (!_.isFinite(target_position)) return;

        command_seek_rotation_slider.value = target_position;

        for (const {motor_controller: controller} of opened_ports.values()) {
          if (!controller) continue;

          controller.send_command({
            message_code: MessageCode.SET_STATE_SEEK_ANGLE_WITH_POWER,
            timeout: command_timeout,
            target_angle: command_angle,
            max_drive_power: controller === motor_controller ? 0 : command_power,
            target_rotation: target_position,
          });
        }
      });

    }],

    ["Match all positions", function(){

      start_command_loop(() => {
        const target_position = get_average_position();
        if (!_.isFinite(target_position)) return;

        command_seek_rotation_slider.value = target_position;

        for (const {motor_controller: controller} of opened_ports.values()) {
          if (!controller) continue;

          controller.send_command({
            message_code: MessageCode.SET_STATE_SEEK_ANGLE_WITH_POWER,
            timeout: command_timeout,
            target_angle: command_angle,
            max_drive_power: command_power,
            target_rotation: target_position,
          });
        }
      });

    }],
  ],
  {label: "Multi-motor control"},
);
d3.select(shared_seek_buttons).selectAll("button").style("height", "4em");

invalidation.then(stop_command_loop);
```

```js

// Readout Plotting
// ----------------

const max_timeline_period = 2000; // ms

const history_duration = Math.ceil(HISTORY_SIZE * millis_per_cycle);

const time_period_input = Inputs.range([1, max_timeline_period], {
  value: max_timeline_period,
  transform: Math.log,
  step: 0.5,
  label: "Time window Duration (ms):",
});

const time_offset_input = inputs_wide_range([0, 1.0], {
  value: 1.0, 
  step: 0.01,
  label: "Time window Offset (ms):",
});

const plot_curve_input = Inputs.radio(new Map([
  ["Connected steps", d3.curveStep],
  ["Interrupted steps", horizontal_step],
  ["Linear", d3.curveLinear],
  ["Smooth", d3.curveCatmullRom],
  ["Step after", d3.curveStepAfter],
  ["Step before", d3.curveStepBefore],
  ]),
  {
    value: d3.curveStep, 
    label: "Drawing options:",
  },
);

const plot_curve = Generators.input(plot_curve_input);

const timeline_position_input = plot_line({
  subtitle: "Time Window Selection",
  description: "Select the time window to plot; drag or resize. Click to see all.",
  width: 1200, height: 150,
  x: "time",
  x_label: "Time (ms)",
  y_label: "Electric position (radians)",
  y_domain: [-Math.PI, Math.PI],
  y: "angle", 
  color: colors.angle,
  include_brush: true,
});

const timeline_position = Generators.input(timeline_position_input);

timeline_position_input.addEventListener("input", function(){
  const {selection} = timeline_position_input.value;  
  if (selection){
    time_period_input.value = (selection[1] - selection[0]) * max_timeline_period;
    const max_choice = (max_timeline_period - time_period_input.value) / max_timeline_period;
    time_offset_input.value = selection[0] / max_choice;
  } else {
    time_period_input.value = max_timeline_period;
    time_offset_input.value = 0;
  }
});

function merge_timeline_inputs(){
  const max_choice = (max_timeline_period - time_period_input.value) / max_timeline_period;

  merge_input_value(timeline_position_input, {
    selection: time_period_input.value === max_timeline_period ? null : [
      time_offset_input.value * max_choice,
      time_offset_input.value * max_choice + (time_period_input.value / max_timeline_period),
    ],
  });
}

time_period_input.addEventListener("input", merge_timeline_inputs);
time_offset_input.addEventListener("input", merge_timeline_inputs);
merge_timeline_inputs();

```

```js
function filter_window(data, time_domain){
  return data.filter((d) => d.time >= time_domain[0] && d.time <= time_domain[1]);
}

// Pick evenly spaced data points to pass to the plot; we can't draw more pixels than we have.
function sparsify(data, target_points = 1080){
  const max_plot_points = target_points;
  const plot_points_skip = Math.ceil(data.length / max_plot_points);
  return data.filter(({readout_index}) => readout_index % plot_points_skip === 0);
}

const timeline_end = data.length == 0 ? 0 : data[data.length - 1].time;
const timeline_start = data.length == 0 ? -16 : Math.max(data[0].time, timeline_end - max_timeline_period);
const timeline_period = timeline_end - timeline_start;
const timeline_domain = [timeline_start, timeline_end];

timeline_position_input.update({
  data: sparsify(filter_window(data, timeline_domain)), 
  x_domain: timeline_domain,
});

const selected_time_domain = !timeline_position.selection ? [timeline_start, timeline_end] : [
  timeline_position.selection[0] * timeline_period + timeline_start,
  timeline_position.selection[1] * timeline_period + timeline_start,
];

const data_in_time_window = sparsify(filter_window(data, selected_time_domain));

Object.values(monitoring_plots).forEach((plot) => plot.update({
  data: data_in_time_window, 
  x_domain: selected_time_domain,
}));
```

```js

const curve = plot_curve;

const plot_power = plot_lines({
  subtitle: "Power",
  description: "Power consumed by the motor.",
  width: 1200, height: 300,
  x: "time",
  x_label: "Time (ms)",
  y_label: "Power (W)",
  channels: [
    {y: "total_power", label: "Total Power", color: colors.sum},
    {y: "total_power_average", label: "Total Power (on chip average)", color: d3.color(colors.sum).darker(1)},
    {
      y: "total_power_avg", label: "Total Power (2ms average)", color: d3.color(colors.sum).darker(1),
      draw_extra: setup_stdev_95({stdev: (d) => d.total_power_stdev}),
    },
    {y: "resistive_power", label: "Resistive Power", color: colors.web_current_magnitude},
    {y: "resistive_power_average", label: "Resistive Power (on chip average)", color: d3.color(colors.web_current_magnitude).darker(1)},
    {y: "emf_power", label: "EMF Power", color: colors.angle},
    {
      y: "emf_power_avg", label: "EMF Power (2ms average)", color: d3.color(colors.angle).darker(1),
      draw_extra: setup_stdev_95({stdev: (d) => d.emf_power_stdev}),
    },
    {y: "inductive_power", label: "Inductive Power", color: colors.current_angle},
    
    {y: "web_total_power", label: "Total Power (computed online)", color: colors.web_angle},
    {y: "web_emf_power", label: "EMF Power (computed online)", color: colors.u},
    {y: "web_resistive_power", label: "Resistive Power (computed online)", color: colors.v},
    {y: "web_inductive_power", label: "Inductive Power (computed online)", color: colors.w},

  ],
  curve,
});

const plot_runtime_stats = plot_lines({
  subtitle: "Motor driver runtime stats",
  description: "Timing data for the motor driver interrupt routines and the main loop.",
  width: 1200, height: 150,
  x: "time",
  x_label: "Time (ms)",
  y_label: "Update frequency (Hz)",
  channels: [
    {y: "main_loop_rate", label: "Main loop rate", color: colors.sum},
    {y: "adc_update_rate", label: "ADC & PWM rate", color: colors.u},
  ],
  curve,
});

const plot_cycle_loop_stats = plot_lines({
  subtitle: "Motor driver cycle loop stats",
  description: "Timing data for the motor driver cycle loop routines.",
  width: 1200, height: 150,
  x: "time",
  x_label: "Time (ms)",
  y_label: "PWM counter value",
  y_domain: [0, pwm_period],
  channels: [
    {y: "cycle_start_tick", label: "Tick at start", color: colors.u},
    {y: "cycle_end_tick", label: "Tick at end", color: colors.v},
    {y: (d) => (pwm_period + d.cycle_end_tick - d.cycle_start_tick) % pwm_period , label: "Cycle duration", color: colors.w},
    {y: (d) => d.cycle_start_tick - PWM_BASE, label: "Ticks at start since mid cycle", color: d3.color(colors.u).brighter(1)},
  ],
  curve,
});

const plot_electric_position = plot_lines({
  subtitle: "Electric position",
  description: "Angular position of the rotor with respect to the electric phases, 0 when magnetic N is aligned with phase U.",
  width: 1200, height: 200,
  x: "time",
  x_label: "Time (ms)",
  y_label: "Electric position (radians)",
  y_domain: [-Math.PI, Math.PI],
  channels: [
    {y: "angle", label: "Magnet Angle", color: colors.angle},
    {y: "predicted_angle", label: "Predicted Angle", color: d3.color(colors.angle).darker(1)},
    {y: "saliency_angle", label: "Saliency Angle", color: colors_categories[5]},
    {y: (d) => d.saliency_angle * 0.5, label: "Half Saliency Angle", color: d3.color(colors_categories[5]).brighter(1)},
    {y: (d) => /* d.current_detected ?  */d.current_angle/*  : null */, label: "Current Angle", color: colors.web_angle},
    {y: (d) => d.web_current_magnitude > 0.010 ? d.web_current_angle : null, label: "Current Angle (computed online)", color: colors.current_angle},
    {
      y: (d) => d.emf_voltage_angle, label: "EMF Voltage Angle", color: colors.voltage_angle,
      draw_extra: setup_stdev_95({stdev: (d) => d.emf_angle_stdev}),
    },
    {y: (d) => normalize_radians(2*d.emf_voltage_angle)*0.5, label: "EMF Voltage Axis", color: d3.color(colors.voltage_angle).brighter(1)},
    {y: "web_emf_voltage_angle", label: "EMF Voltage Angle (computed online)", color: colors.voltage_angle},
    {y: (d) => d.drive_voltage_magnitude > 0 ? d.drive_voltage_angle : null, label: "Drive Voltage Angle", color: colors_categories[2]},
  ],
  curve,
});

const plot_electric_offsets = plot_lines({
  subtitle: "Electric Offsets",
  description: "Offsets for the electric angles.",
  width: 1200, height: 200,
  x: "time",
  x_label: "Time (ms)",
  y_label: "Angle (radians)",
  channels: [
    {y: (d) => d.current_detected ? d.current_angle_offset : null, label: "Current Angle Offset", color: colors.current_angle},
    {
      y: (d) => d.emf_detected ? d.emf_voltage_angle_offset : null, label: "EMF Voltage Angle Offset", color: colors.voltage_angle,
      draw_extra: setup_stdev_95({stdev: (d) => d.emf_angle_stdev}),
    },
    {y: "angle_adjustment", label: "Magnet Angle Correction", color: d3.color(colors.angle).darker(1)},
    {y: "emf_angle_error", label: "EMF Angle Error", color: d3.color(colors.angle).brighter(1)},
    {y: "emf_angle_stdev", label: "EMF Angle stdev", color: d3.color(colors.voltage_angle).darker(1)},
    {y: "lead_angle", label: "Lead Angle", color: colors.v},
    {y: (d) => d.drive_voltage_magnitude > 0 ? d.drive_voltage_angle_offset : null, label: "Drive Voltage Angle Offset", color: colors_categories[2]},
  ],
  curve,
});

const plot_speed = plot_lines({
  subtitle: "Rotor Speed",
  description: "Angular speed of the rotor in rotations per millisecond.",
  width: 1200, height: 300,
  x: "time",
  x_label: "Time (ms)",
  y_label: "Angular Speed (rotations/ms)",
  channels: [
    {y: "angular_speed", label: "Magnet Angular Speed", color: colors.angular_speed},
    {y: "emf_voltage_angular_speed", label: "EMF Voltage Angular Speed", color: colors.voltage_angle},
    {y: "emf_angular_speed_stdev", label: "EMF Angular Speed stdev", color: colors.angle_driven},
  ],
  curve,
});

const plot_measured_voltage = plot_lines({
  subtitle: "VCC Voltage",
  description: "Measured voltage values for VCC.",
  width: 1200, height: 150,
  x: "time",
  y_domain: [0, 24],
  x_label: "Time (ms)",
  y_label: "Voltage (V)",
  channels: [
    {y: "vcc_voltage", label: "VCC Voltage", color: colors.v},
  ],
  curve,
});

const plot_measured_temperature = plot_lines({
  subtitle: "Temperature",
  description: "Measured temperature values for the MCU.",
  width: 1200, height: 150,
  x: "time",
  y_domain: [0, 100],
  x_label: "Time (ms)",
  y_label: "Temperature (°C)",
  channels: [
    {y: "temperature", label: "MCU Temp (inaccurate)", color: colors.w},
  ],
  curve,
});

const plot_measured_current = plot_lines({
  subtitle: "Currents",
  description: "Measured current values for each phase.",
  width: 1200, height: 400,
  x: "time",
  x_label: "Time (ms)",
  y_label: "Current (A)",
  channels: [
    {y: "u_current", label: "Current U", color: colors.u},
    {y: "v_current", label: "Current V", color: colors.v},
    {y: "w_current", label: "Current W", color: colors.w},
    
    {y: "u_current_diff", label: "Current U diff", color: d3.color(colors.u).darker(1)},
    {y: "v_current_diff", label: "Current V diff", color: d3.color(colors.v).darker(1)},
    {y: "w_current_diff", label: "Current W diff", color: d3.color(colors.w).darker(1)},

    {y: "u_current_zero", label: "Current U 0 offset", color: d3.color(colors.u).brighter(1)},
    {y: "v_current_zero", label: "Current V 0 offset", color: d3.color(colors.v).brighter(1)},
    {y: "w_current_zero", label: "Current W 0 offset", color: d3.color(colors.w).brighter(1)},

    {y: "battery_current", label: "Battery Current", color: colors.other},
    {y: "zero_current", label: "Current Sum/3", color: colors.sum},
    {y: "ref_readout", label: "Reference value", color: colors.ref_readout},
  ],
  curve,
});

const plot_voltages = plot_lines({
  subtitle: "Voltages",
  description: "Measured voltage values for each phase.",
  width: 1200, height: 300,
  x: "time",
  x_label: "Time (ms)",
  y_label: "Voltage (V)",
  channels: [
    {y: "u_drive_voltage", label: "Drive Voltage U", color: colors.u},
    {y: "v_drive_voltage", label: "Drive Voltage V", color: colors.v},
    {y: "w_drive_voltage", label: "Drive Voltage W", color: colors.w},
    {y: "u_R_voltage", label: "Resistive Voltage U", color: d3.color(colors.u).darker(1)},
    {y: "v_R_voltage", label: "Resistive Voltage V", color: d3.color(colors.v).darker(1)},
    {y: "w_R_voltage", label: "Resistive Voltage W", color: d3.color(colors.w).darker(1)},
  ],
  curve,
});

const plot_inferred_voltages = plot_lines({
  subtitle: "Inferred Voltage",
  description: html`Inferred EMF voltage values for each phase: ${tex`V_{emf} = IR + L(dI/dt) - V_{drive}`}.`,
  width: 1200, height: 300,
  x: "time",
  x_label: "Time (ms)",
  y_label: "Voltage (V)",
  channels: [
    {y: "u_emf_voltage", label: "EMF Voltage U", color: colors.u},
    {y: "v_emf_voltage", label: "EMF Voltage V", color: colors.v},
    {y: "w_emf_voltage", label: "EMF Voltage W", color: colors.w},
    {y: "u_L_voltage", label: "Inductor Voltage U", color: d3.color(colors.u).brighter(1)},
    {y: "v_L_voltage", label: "Inductor Voltage V", color: d3.color(colors.v).brighter(1)},
    {y: "w_L_voltage", label: "Inductor Voltage W", color: d3.color(colors.w).brighter(1)},
    {y: "u_partial_voltage", label: "Partial Voltage U", color: d3.color(colors.u).darker(1)},
    {y: "v_partial_voltage", label: "Partial Voltage V", color: d3.color(colors.v).darker(1)},
    {y: "w_partial_voltage", label: "Partial Voltage W", color: d3.color(colors.w).darker(1)},
  ],
  curve,
});

const plot_dq0_currents = plot_lines({
  subtitle: "DQ0 Currents",
  description: "DQ0 currents after Clarke and Park (direct-quadrature-zero) transforming the measured currents.",
  width: 1200, height: 400,
  x: "time",
  x_label: "Time (ms)",
  y_label: "Current (A)",
  channels: [
    {y: "direct_current", label: "Current on Direct axis", color: colors.direct_current},
    {y: "quadrature_current", label: "Current on Quadrature", color: colors.quadrature_current},
    {y: "prev_direct_current", label: "Previous Current on Direct axis", color: d3.color(colors.direct_current).darker(1)},
    {y: "prev_quadrature_current", label: "Previous Current on Quadrature axis", color: d3.color(colors.quadrature_current).darker(1)},
    {y: "prev_current_magnitude", label: "Previous Current Magnitude", color: d3.color(colors_categories[2]).darker(1)},
    {y: "current_magnitude", label: "Current Magnitude", color: colors_categories[2]},
    {y: "web_direct_current", label: "Current on Direct axis (computed online)", color: d3.color(colors.direct_current).brighter(1)},
    {y: "web_quadrature_current", label: "Current on Quadrature (computed online)", color: d3.color(colors.quadrature_current).brighter(1)},
    {y: "steady_state_drive_current", label: "Drive Current if stalling", color: d3.color(colors.direct_current).darker(1)},
    {y: "web_current_magnitude", label: "Current Magnitude (computed online)", color: colors.web_current_magnitude},
    {
      y: "web_current_magnitude_avg", label: "Current Magnitude (2ms average)", color: d3.color(colors.web_current_magnitude).brighter(1),
      draw_extra: setup_stdev_95({stdev: (d) => d.web_current_magnitude_stdev}),
    },
  ],
  curve,
});

const plot_dq0_voltages = plot_lines({
  subtitle: "DQ0 Voltages",
  description: "DQ0 voltages after Clarke and Park (direct-quadrature-zero) transforming the inferred voltages.",
  width: 1200, height: 400,
  x: "time",
  x_label: "Time (ms)",
  y_label: "Voltage (V)",
  channels: [
    {y: "direct_emf_voltage", label: "EMF Voltage on Direct axis", color: colors.direct_current},
    {y: "quadrature_emf_voltage", label: "EMF Voltage on Quadrature", color: colors.quadrature_current},
    {y: "emf_voltage_magnitude", label: "EMF Voltage Magnitude", color: colors.web_current_magnitude},
    {y: "emf_angle_stdev", label: "EMF Voltage Stdev", color: d3.color(colors.web_current_magnitude).darker(1)},
    {y: "web_direct_emf_voltage", label: "Voltage on Direct axis (computed online)", color: d3.color(colors.direct_current).brighter(1)},
    {y: "web_quadrature_emf_voltage", label: "Voltage on Quadrature (computed online)", color: d3.color(colors.quadrature_current).brighter(1)},
    {y: "web_emf_voltage_magnitude", label: "Voltage Magnitude (computed online)", color: colors.web_current_magnitude},
    {
      y: "web_emf_voltage_magnitude_avg", label: "Voltage Magnitude (2ms average)", color: d3.color(colors.web_current_magnitude).brighter(1),
      draw_extra: setup_stdev_95({stdev: (d) => d.web_emf_voltage_magnitude_stdev}),
    },
    {y: "drive_voltage_magnitude", label: "Drive Voltage Magnitude", color: colors_categories[2]},
  ],
  curve,
});

const plot_pwm_settings = plot_lines({
  subtitle: "PWM Settings",
  description: "The PWM value currently set for each phase.",
  width: 1200, height: 300,
  x: "time",
  x_label: "Time (ms)",
  y_label: "PWM",
  channels: [
    {y: "u_pwm", label: "PWM U", color: colors.u},
    {y: "v_pwm", label: "PWM V", color: colors.v},
    {y: "w_pwm", label: "PWM W", color: colors.w},
    {y: "live_max_pwm", label: "Live Max PWM", color: colors_categories[0]},
    {y: "active_pwm", label: "Active PWM", color: colors_categories[1]},
  ],
  curve,
});

const plot_readout_flags = plot_lines({
  subtitle: "Readout Flags",
  description: "Flags indicating the state of the readouts.",
  width: 1200, height: 150,
  x: "time",
  x_label: "Time (ms)",
  y_label: "Flag setting",
  channels: [
    {y: "emf_detected", label: "EMF detected", color: colors_categories[3]},
    {y: "emf_fix", label: "EMF speed fix", color: colors_categories[4]},
    {y: "current_detected", label: "Current detected", color: colors_categories[6]},
    {y: "angle_fix", label: "Rotor position fix", color: colors_categories[7]},
    {y: "nominal_vcc_voltage", label: "Nominal VCC Voltage", color: colors_categories[8]},
    {y: "overpowered", label: "Overpowered", color: colors_categories[9]},
    {y: "overheating", label: "Overheating", color: colors_categories[10]},
    {y: "hall_u", label: "Hall U", color: colors.u},
    {y: "hall_v", label: "Hall V", color: colors.v},
    {y: "hall_w", label: "Hall W", color: colors.w},
  ],
  curve,
});

const plot_motor_values = plot_lines({
  subtitle: "Motor Values",
  description: "Various values related to the motor's operation.",
  width: 1200, height: 400,
  x: "time",
  x_label: "Time (ms)",
  y_label: "Value",
  channels: [
    {y: "rotations", label: "Rotations", color: colors_categories[1]},
    {y: "target", label: "Target", color: colors_categories[2]},
    {y: "seek_integral", label: "Seek Integral", color: colors_categories[3]},
    {y: "resistance", label: "Phase Resistance", color: colors.u},
    {y: "inductance", label: "Phase Inductance", color: colors.v},
    {y: "inductance_bias", label: "Inductance Bias", color: colors_categories[4]},
    {y: "motor_constant", label: "Motor Constant (EMF and torque)", color: colors.angle},
  ],
  curve,
});

const monitoring_plots = {
  plot_power,
  plot_runtime_stats,
  plot_cycle_loop_stats,
  plot_electric_position,
  plot_electric_offsets,
  plot_speed,
  plot_measured_voltage,
  plot_measured_temperature,
  plot_measured_current,
  plot_voltages,
  plot_inferred_voltages,
  plot_dq0_currents,
  plot_dq0_voltages,
  plot_pwm_settings,
  plot_readout_flags,
  plot_motor_values,
};

autosave_inputs(monitoring_plots);
```

```js
// Current calibration
// -------------------

const current_calibration_pwm_slider = inputs_wide_range([0, PWM_BASE], {value: PWM_BASE * 0.04, step: 1.0, label: "Calibration max PWM:"});

const current_calibration_pwm = Generators.input(current_calibration_pwm_slider);

const current_calibration_test_speed_slider = inputs_wide_range(
  [
    -speed_units_to_rotations_per_millisecond(max_angular_speed), 
    +speed_units_to_rotations_per_millisecond(max_angular_speed)
  ], 
  {value: 1.0, label: "Calibration test speed (rotations/ms):"});

const current_calibration_test_speed = transformed_input_value(current_calibration_test_speed_slider, rotations_per_millisecond_to_speed_units);

const current_calibration_test_duration_slider = inputs_wide_range([0, 16*HISTORY_SIZE], {value: HISTORY_SIZE, step: 1, label: "Calibration test duration:"});

const current_calibration_duration = Generators.input(current_calibration_test_duration_slider);

// Choose the target angle for certain commands.
const current_calibration_angle_slider = inputs_wide_range([-Math.PI, Math.PI], {value: 0, step: 0.01, label: "Command angle (radians):"});
const current_calibration_angle = transformed_input_value(current_calibration_angle_slider, radians_to_angle_units);

function stringify_active_current_calibration() {
  return `motor_controller.current_calibration = ${JSON.stringify(motor_controller?.current_calibration, null, 2)}`;
}

const active_current_calibration_table =  Mutable(stringify_active_current_calibration());

const calibration_parameters = {
  u_current_zero: {
    label: "U Current Zero", 
    description: `The zero-current offset for the U phase.`
  },
  v_current_zero: {
    label: "V Current Zero", 
    description: `The zero-current offset for the V phase.`
  },
  w_current_zero: {
    label: "W Current Zero", 
    description: `The zero-current offset for the W phase.`
  },
  resistance: {
    label: "Resistance", 
    description: `The resistance of average phase coil.`
  },
  inductance: {
    label: "Phase Inductance", 
    description: `The inductance of the motor's phases.`
  },
  inductance_bias: {
    label: "Inductance Bias", 
    description: `The bias of the motor's phase inductance.`
  },
  saturation_factor: {
    label: "Saturation Factor", 
    description: `The factor of the motor's saturation.`
  },
  motor_constant: {
    label: "Motor Constant", 
    description: `The motor constant, which relates torque and current, or speed and emf.`
  },
}

const current_calibration_input = Object.fromEntries(
  Object.entries(calibration_parameters).map(([key, {label, description}]) => {
    
    let parameter_input = Inputs.number([], {
      label,
      value: motor_controller?.current_calibration?.[key],
    });

    d3.select(parameter_input).style("width", "100%").style("margin", "1em 0em 1em 0em")
      .select("div").style("width", "50em")
        .append("span").text(description).style("margin", "0em 1em 0em 1em").style("width", "100em");

    return [key, parameter_input];
  })
);

const current_calibration_checkboxes = enabled_checkbox(Object.entries(calibration_parameters).map(([key, {label, description}]) => label));
  
function get_checked_parameters(){
  return Object.fromEntries(
    Object.entries(calibration_parameters).map(([key, {label}]) => {
      return [key, current_calibration_checkboxes.value.includes(label)];
    })
  );
}

function show_active_current_calibration() {
  active_current_calibration_table.value = stringify_active_current_calibration();
  Object.entries(current_calibration_input).forEach(([key, input]) => {
    input.value = motor_controller?.current_calibration?.[key];
  });
}

const current_calibration_data = Mutable(null);

const update_current_calibration_data = (new_value) => {
  current_calibration_data.value = new_value;
  if (new_value.is_stable) {
    Object.entries(current_calibration_input).forEach(([key, input]) => {
      input.value = new_value.current_calibration[key];
    });
  }
};
```

```js

async function run_current_calibration(motor_controller, message_options) {
  if (!motor_controller.current_calibration) {
    console.error("We didn't load the active calibration data from the driver, we can't proceed without it.");
    throw new Error("Missing current calibration data");
  }

  const current_calibration = {...motor_controller.current_calibration};
  const control_parameters = motor_controller.control_parameters;

  // console.info("Starting motor spin...");
  // await motor_controller.send_command({
  //   message_code: MessageCode.SET_STATE_DRIVE_SMOOTH,
  //   timeout: Math.floor(1000 * cycles_per_millisecond),
  //   pwm_value: +command_pwm,
  // });

  // await wait(1000);

  console.info("Current calibration starting");

  // Run a calibration instance.
  let sample = await motor_controller.send_command_and_await_reply({
    message: {
      ...message_options,
      take_snapshot: 1,
    },
    expected_messages: HISTORY_SIZE,
    expected_code: MessageCode.READOUT,
  });
  
  // Check all calibration data is complete.
  if (sample.length !== HISTORY_SIZE) {
    console.error("Calibration data incomplete", sample);
    return;
  }

  // Test if we've had nominal VCC voltage throughout the calibration run.
  const all_nominal_vcc_voltage = sample.every(({nominal_vcc_voltage}) => nominal_vcc_voltage);

  if (!all_nominal_vcc_voltage) {
    console.warn("Nominal VCC voltage was not maintained during the calibration run, we can't trust the drive voltage.");
    return {
      sample,
      is_stable: false,
    }
  }

  const enabled_parameters = get_checked_parameters();

  const min_speed = speed_units_to_rotations_per_millisecond(control_parameters?.min_emf_speed);

  // Test if the voltage was mostly 0.
  const count_idle = sample.filter(({u_drive_voltage, v_drive_voltage, w_drive_voltage, angular_speed}) => 
    Math.abs(u_drive_voltage) < 0.001 && 
    Math.abs(v_drive_voltage) < 0.001 && 
    Math.abs(w_drive_voltage) < 0.001 &&
    Math.abs(angular_speed) < min_speed
  ).length;

  // For all 0 voltages we calibrate the baseline offset of the currents.
  if (count_idle === sample.length) {
    console.info("All drive voltages are zero, calibrating current baseline offsets.");
    const u_current_zero = sample.reduce((sum, {u_current}) => sum + u_current, 0) / sample.length + current_calibration?.u_current_zero;
    const v_current_zero = sample.reduce((sum, {v_current}) => sum + v_current, 0) / sample.length + current_calibration?.v_current_zero;
    const w_current_zero = sample.reduce((sum, {w_current}) => sum + w_current, 0) / sample.length + current_calibration?.w_current_zero; 
  
    return {
      sample,
      is_stable: true,
      iterations: [
        {
          iteration: 0,
          current_calibration: {
            u_current_zero,
            v_current_zero,
            w_current_zero,
          },
          sample
        }
      ],
      current_calibration: {
        u_current_zero,
        v_current_zero,
        w_current_zero,
      }
    }
  }

  const max_iterations = 1000;
  const relative_stability = 0.001;
  const relative_min = relative_stability / 10;
  const relative_initial = 0.1;
  const relative_increase = 1.2;
  const relative_decrease = 0.5;

  class Parameter {
    constructor({value, max_learning_rate}) {
      this.value = value;
      this.max_learning_rate = max_learning_rate;
      this.learning_rate = max_learning_rate * relative_initial;
      this.sign = 0;
    }

    reset(value) {
      this.value = value;
      this.learning_rate = this.max_learning_rate * relative_initial;
      this.sign = 0;
    }
  }

  let parameters = {
    resistance: new Parameter({
      value: current_calibration?.resistance ?? 0.01,
      max_learning_rate: 0.1,
    }),
    inductance: new Parameter({
      value: current_calibration?.inductance ?? 0.00001, 
      max_learning_rate: 0.000_01,
    }),
    inductance_bias: new Parameter({
      value: current_calibration?.inductance_bias ?? 0.0,
      max_learning_rate: 0.000_01,
    }),
    saliency_angle: new Parameter({
      value: 0.0,
      max_learning_rate: Math.PI / 4,
    }),
    saturation_factor: new Parameter({
      value: current_calibration?.saturation_factor ?? 0.0,
      max_learning_rate: 0.000_01,
    }),
    saturation_angle: new Parameter({
      value: 0.0,
      max_learning_rate: Math.PI / 4,
    }),
    motor_constant: new Parameter({
      value: current_calibration?.motor_constant ?? 0.0,
      max_learning_rate: 0.000_01,
    }),
  };

  const angle_deltas = sample.map((d) => new Parameter({
    value: 0.0,
    max_learning_rate: Math.PI / 96,
  }));

  let is_stable = false;

  let iterations = [];

  for (let i = 0; !is_stable && (i < max_iterations); i++) {

    const {
      resistance,
      inductance,
      inductance_bias,
      saliency_angle,
      saturation_factor,
      saturation_angle,
      motor_constant,
    } = Object.fromEntries(Object.entries(parameters).map(([key, param]) => [key, param.value]));

    const sample_forward_pass = sample.map((readout, i) => {
      const {
        direct_current, quadrature_current,
        direct_current_diff, quadrature_current_diff,
        direct_drive_voltage, quadrature_drive_voltage,

        angular_speed, angle, emf_voltage_angular_speed,
      } = readout;

      const angle_delta = angle_deltas[i].value;
      const true_angle = normalize_radians(angle + angle_delta);

      const d_di_dt = direct_current_diff * pwm_cycles_per_second;
      const q_di_dt = quadrature_current_diff * pwm_cycles_per_second;

      const direct_resistive_voltage = direct_current * resistance;
      const quadrature_resistive_voltage = quadrature_current * resistance;

      const A_saturation = direct_current * d_di_dt - quadrature_current * q_di_dt;
      const B_saturation = quadrature_current * d_di_dt + direct_current * q_di_dt;

      const K_saturation = parameters.saturation_factor.value;

      const K_motor = parameters.motor_constant.value;

      // Convert to radians per second.
      const omega = normalize_radians(
        i > 0 ? (
          normalize_radians(angle + angle_delta) -
          normalize_radians(sample[i - 1].angle + angle_deltas[i - 1].value)
        ) : (
          normalize_radians(sample[i + 1].angle + angle_deltas[i + 1].value) -
          normalize_radians(angle + angle_delta)
        )
      ) * pwm_cycles_per_second;

      const direct_inductance_bias_voltage = (
        -d_di_dt * inductance_bias * Math.cos(2 * saliency_angle) +
        -q_di_dt * inductance_bias * Math.sin(2 * saliency_angle)
      );

      const quadrature_inductance_bias_voltage = (
        -d_di_dt * inductance_bias * Math.sin(2 * saliency_angle) +
        +q_di_dt * inductance_bias * Math.cos(2 * saliency_angle)
      );

      const direct_inductance_saturation_voltage = (
        K_saturation * A_saturation * Math.cos(saturation_angle) +
        -K_saturation * B_saturation * Math.sin(saturation_angle)
      );

      const quadrature_inductance_saturation_voltage = (
        K_saturation * A_saturation * Math.sin(saturation_angle) +
        K_saturation * B_saturation * Math.cos(saturation_angle)
      );

      const direct_inductance_voltage = (
        d_di_dt * inductance + 
        direct_inductance_bias_voltage +
        direct_inductance_saturation_voltage
      );

      const quadrature_inductance_voltage = (
        q_di_dt * inductance +
        quadrature_inductance_bias_voltage +
        quadrature_inductance_saturation_voltage
      );

      const direct_emf_voltage = K_motor * omega * Math.sin(angle_delta);
      const quadrature_emf_voltage = - K_motor * omega * Math.cos(angle_delta);

      const direct_residual = direct_resistive_voltage + direct_inductance_voltage - direct_drive_voltage - direct_emf_voltage;
      const quadrature_residual = quadrature_resistive_voltage + quadrature_inductance_voltage - quadrature_drive_voltage - quadrature_emf_voltage;

      const residual_angle = Math.atan2(quadrature_residual, direct_residual);

      const two_current_angle = normalize_radians(2 * (angle + Math.atan2(quadrature_current, direct_current)));

      const loss = square(direct_residual) + square(quadrature_residual);

      const sqrt_loss = Math.sqrt(loss);

      return {
        ...readout,
        
        direct_resistive_voltage,
        quadrature_resistive_voltage,

        direct_inductance_bias_voltage,
        quadrature_inductance_bias_voltage,
        direct_inductance_saturation_voltage,
        quadrature_inductance_saturation_voltage,

        direct_inductance_voltage,
        quadrature_inductance_voltage,
        direct_emf_voltage,
        quadrature_emf_voltage,

        angle_delta,
        true_angle,
        d_di_dt,
        q_di_dt,
        A_saturation,
        B_saturation,
        K_saturation,
        omega,

        loss,
        sqrt_loss,
        
        direct_residual,
        quadrature_residual,
        residual_angle,
        two_current_angle,
      };
    });

    const sample_gradients = sample_forward_pass.map((readout, i) => {
      const {
        direct_residual,
        quadrature_residual,
        direct_current,
        quadrature_current,
        
        angle_delta,
        d_di_dt,
        q_di_dt,
        A_saturation,
        B_saturation,
        K_saturation,
        omega,
      } = readout;
      
      const resistance_gradient = (
        direct_residual * direct_current +
        quadrature_residual * quadrature_current
      );

      const inductance_gradient = (
        direct_residual * d_di_dt +
        quadrature_residual * q_di_dt
      );

      const inductance_bias_gradient = (
        direct_residual * (
          -d_di_dt * Math.cos(2 * saliency_angle) +
          -q_di_dt * Math.sin(2 * saliency_angle)
        ) +
        quadrature_residual * (
          -d_di_dt * Math.sin(2 * saliency_angle) +
          +q_di_dt * Math.cos(2 * saliency_angle)
        )
      );

      const saliency_angle_gradient = (
        2 * inductance_bias * direct_residual * (
          +d_di_dt * Math.sin(2 * saliency_angle) +
          -q_di_dt * Math.cos(2 * saliency_angle)
        ) +
        2 * inductance_bias * quadrature_residual * (
          -d_di_dt * Math.cos(2 * saliency_angle) +
          -q_di_dt * Math.sin(2 * saliency_angle)
        )
      );

      const saturation_factor_gradient = (
        2 * direct_residual * (
          A_saturation * Math.cos(saturation_angle) +
          -B_saturation * Math.sin(saturation_angle)
        ) + 
        2 * quadrature_residual * (
          A_saturation * Math.sin(saturation_angle) +
          B_saturation * Math.cos(saturation_angle)
        )
      );

      const saturation_angle_gradient = (
        2 * K_saturation * direct_residual * (
          -A_saturation * Math.sin(saturation_angle) +
          -B_saturation * Math.cos(saturation_angle)
        ) +
        2 * K_saturation * quadrature_residual * (
          A_saturation * Math.cos(saturation_angle) +
          -B_saturation * Math.sin(saturation_angle)
        )
      );

      const motor_constant_gradient = (
        -direct_residual * omega * Math.sin(angle_delta) +
        quadrature_residual * omega * Math.cos(angle_delta)
      );

      const angle_delta_gradient_position = (
        -direct_residual * omega * Math.cos(angle_delta) +
        -quadrature_residual * omega * Math.sin(angle_delta)
      );

      const angle_delta_gradient_speed = (
        -direct_residual * motor_constant * Math.sin(angle_delta) * pwm_cycles_per_second +
        quadrature_residual * motor_constant * Math.cos(angle_delta) * pwm_cycles_per_second
      );

      const angle_delta_gradient = (
        angle_delta_gradient_speed + 
        angle_delta_gradient_position
      );

      return {
        ...readout,
        resistance_gradient,
        inductance_gradient,
        inductance_bias_gradient,
        saliency_angle_gradient,
        saturation_factor_gradient,
        saturation_angle_gradient,
        motor_constant_gradient,
        angle_delta_gradient,
        angle_delta_gradient_speed,
        angle_delta_gradient_position,
      };
    });

    let rotor_axis_prediction = normalize_radians(2*(parameters.saliency_angle.value + sample.slice(-1)[0].angle));

    iterations.push({
      iteration: i,
      current_calibration: {
        sqrt_loss: Math.sqrt(d3.mean(sample_gradients, (d) => d.loss)),
        resistance: parameters.resistance.value,
        inductance: parameters.inductance.value,
        inductance_bias: parameters.inductance_bias.value,
        saliency_angle: normalize_radians(2*(parameters.saliency_angle.value))/2,
        saturation_factor: parameters.saturation_factor.value,
        saturation_angle: parameters.saturation_angle.value,
        motor_constant: parameters.motor_constant.value,

        rotor_axis_prediction,

        resistance_learning_rate: parameters.resistance.learning_rate,
        inductance_learning_rate: parameters.inductance.learning_rate,
        inductance_bias_learning_rate: parameters.inductance_bias.learning_rate,
        saliency_angle_learning_rate: parameters.saliency_angle.learning_rate,
        saturation_factor_learning_rate: parameters.saturation_factor.learning_rate,
        saturation_angle_learning_rate: parameters.saturation_angle.learning_rate,
        motor_constant_learning_rate: parameters.motor_constant.learning_rate,
      },
      sample: sample_gradients,
    });

    // Resilient Backpropagation
    // -------------------------
    // 
    // Update steps and learning rates using the sign of the gradient to the unexplained residual loss.

    is_stable = true;

    const gradients = {
      resistance: d3.mean(sample_gradients, (d) => d.resistance_gradient),
      inductance: d3.mean(sample_gradients, (d) => d.inductance_gradient),
      inductance_bias: d3.mean(sample_gradients, (d) => d.inductance_bias_gradient),
      saliency_angle: d3.mean(sample_gradients, (d) => d.saliency_angle_gradient),
      saturation_factor: d3.mean(sample_gradients, (d) => d.saturation_factor_gradient),
      saturation_angle: d3.mean(sample_gradients, (d) => d.saturation_angle_gradient),
      motor_constant: d3.mean(sample_gradients, (d) => d.motor_constant_gradient),
    }

    function resilient_update(parameter, gradient) {
      const new_sign = Math.sign(gradient);
      if ((new_sign == 0.0) || (new_sign != parameter.sign)) {
        parameter.learning_rate = Math.max(relative_min * parameter.max_learning_rate, parameter.learning_rate * relative_decrease);
      } else {
        parameter.learning_rate = Math.min(parameter.max_learning_rate, parameter.learning_rate * relative_increase);
      }

      parameter.value -= parameter.learning_rate * new_sign;
      parameter.sign = new_sign;

      return parameter.learning_rate < (parameter.max_learning_rate * relative_stability);
    }

    for (const [key, gradient] of Object.entries(gradients)) {
      if (!enabled_parameters[key]) continue;

      if (!resilient_update(parameters[key], gradient)) {
        is_stable = false;
      }
    }

    if (enabled_parameters.angle_delta) {
      angle_deltas.forEach((angle_delta_parameter, i) => {
        if (!resilient_update(angle_delta_parameter, sample_gradients[i].angle_delta_gradient)) {
          is_stable = false;
        }
      });
    }
    
    // Update calibration values after pushing the iteration data! The iteration should then
    // contain the calibration values that were used to calculate the gradients and other values.

    if (parameters.resistance.value < 0.0) parameters.resistance.reset(0.0);
    if (parameters.inductance.value < 0.0) parameters.inductance.reset(0.0);

    if (parameters.inductance_bias.value < 0.0) {
      parameters.inductance_bias.reset(0.0);
      parameters.saliency_angle.value = parameters.saliency_angle.value + Math.PI/12;
    }

    if (parameters.saturation_factor.value < 0.0) {
      parameters.saturation_factor.reset(- 0.5 * parameters.saturation_factor.value);
      parameters.saturation_angle.value = parameters.saturation_angle.value + Math.PI/12;
    }

    parameters.saliency_angle.value = normalize_radians(parameters.saliency_angle.value);
    parameters.saturation_angle.value = normalize_radians(parameters.saturation_angle.value);
    
    if (parameters.motor_constant.value < 0.0) parameters.motor_constant.reset(0.0);
  }

  const current_calibration_data = {
    sample,
    is_stable,
    iterations,
    current_calibration: {
      resistance: parameters.resistance.value,
      inductance: parameters.inductance.value,
      inductance_bias: parameters.inductance_bias.value,
      saliency_angle: parameters.saliency_angle.value,
      saturation_factor: parameters.saturation_factor.value,
      saturation_angle: parameters.saturation_angle.value,
      motor_constant: parameters.motor_constant.value,
    }
  };

  return current_calibration_data;
}

async function run_current_calibration_by_code(message_code) {
  if (!motor_controller) return;
  const calibration_data = await run_current_calibration(
    motor_controller, 
    {
      message_code,
      pwm_value: current_calibration_pwm,
      test_speed: current_calibration_test_speed,
      test_duration: current_calibration_duration,
      test_angle: current_calibration_angle,
    }
  );
  update_current_calibration_data(calibration_data);
  // set_readout_series(calibration_data.sample, active_port);
}

const current_calibration_run_buttons = Inputs.button(
  test_buttons_to_code.map(([label, code]) => [label, () => run_current_calibration_by_code(code)]),
  {label: "Run calibration sequence"},
);
d3.select(current_calibration_run_buttons).selectAll("button").style("height", "4em");

const current_calibration_buttons = !motor_controller ? html`<p>Not connected to motor!</p>` : Inputs.button(
  [
    ["Upload to Driver", async function(){
      if (!motor_controller) return;
      const current_calibration = {
        ...motor_controller.current_calibration,
        ...Object.fromEntries(Object.entries(current_calibration_input).map(([key, input]) => [key, input.value])),
      };
      await motor_controller.upload_current_calibration(current_calibration);
      show_active_current_calibration();
      unsaved_changes();
    }],
    ["Reload from Driver", async function(){
      await motor_controller.load_current_calibration();
      show_active_current_calibration();
    }],
    ["Reset to Defaults", async function(){
      await motor_controller.reset_current_calibration();
      show_active_current_calibration();
      unsaved_changes();
    }],
  ],
  {
    label: "Current Calibration",
  },
);

d3.select(current_calibration_buttons).style("width", "100%");
```

```js
const current_calibration_iterations = current_calibration_data?.iterations ?? [];

// Select the optimization iteration to display.
const current_calibration_optimization_iteration_input = !current_calibration_data ? 
  html`<p>No optimization iterations available.</p>` : 
  inputs_wide_range(
    [0, current_calibration_iterations.length - 1], {
    step: 1,
    label: "Select optimization iteration to display:",
  });

const current_calibration_optimization_iteration = Generators.input(current_calibration_optimization_iteration_input);

set_input_value(current_calibration_optimization_iteration_input, current_calibration_iterations?.length - 1);

```

```js

const current_calibration_iteration = current_calibration_iterations[current_calibration_optimization_iteration];
const current_calibration_gradients = current_calibration_iteration?.sample ?? [];

// Write out the current calibration results in copyable format.
const current_calibration_iteration_table = `current_calibration = ${JSON.stringify(current_calibration_iterations[current_calibration_optimization_iteration]?.current_calibration, null, 2)}`;

const current_calibration_optimizing_plot = plot_lines({
  data: current_calibration_gradients,
  subtitle: "Current Calibration - Optimizing resistance & inductance",
  description: "Current calibration optimization results for each phase.",
  width: 1200, height: 300,
  x_domain: [0, HISTORY_SIZE * millis_per_cycle],
  x: "time",
  x_label: "Time (ms)",
  y_label: "Voltage (V)",
  channels: [
    {y: "direct_drive_voltage", label: "Direct Drive Voltage", color: d3.color(colors.u).brighter(1)},
    {y: "quadrature_drive_voltage", label: "Quadrature Drive Voltage", color: d3.color(colors.v).brighter(1)},

    {y: "direct_resistive_voltage", label: "Direct Resistance Drop", color: colors.u},
    {y: "quadrature_resistive_voltage", label: "Quadrature Resistance Drop", color: colors.v},

    {y: "direct_inductance_voltage", label: "Direct Inductance Drop", color: d3.color(colors.u).darker(1)},
    {y: "quadrature_inductance_voltage", label: "Quadrature Inductance Drop", color: d3.color(colors.v).darker(1)},

    {y: "direct_emf_voltage", label: "Direct EMF Voltage", color: d3.color(colors.u).darker(1)},
    {y: "quadrature_emf_voltage", label: "Quadrature EMF Voltage", color: d3.color(colors.v).darker(1)},
    {y: "omega", label: "Omega", color: colors.angular_speed},
    {y: "emf_voltage_angular_speed", label: "EMF Angular Speed", color: d3.color(colors.angular_speed).darker(1)},

    {y: "direct_inductance_bias_voltage", label: "Direct Inductance Bias", color: d3.color(colors.u).darker(1)},
    {y: "quadrature_inductance_bias_voltage", label: "Quadrature Inductance Bias", color: d3.color(colors.v).darker(1)},
    {y: "direct_inductance_saturation_voltage", label: "Direct Inductance Saturation", color: d3.color(colors.u).darker(2)},
    {y: "quadrature_inductance_saturation_voltage", label: "Quadrature Inductance Saturation", color: d3.color(colors.v).darker(2)},

    {y: "direct_residual", label: "Direct Residual", color: d3.color(colors.u).darker(2)},
    {y: "quadrature_residual", label: "Quadrature Residual", color: d3.color(colors.v).darker(2)},

    {y: "sqrt_loss", label: "Sqrt Loss", color: d3.color(colors_categories[2]).darker(1)},

  ],
  curve,
});

const current_calibration_angles_plot = plot_lines({
  data: current_calibration_gradients,
  subtitle: "Current Calibration - Optimizing angles",
  description: "Current calibration optimization results for each phase.",
  width: 1200, height: 300,
  x_domain: [0, HISTORY_SIZE * millis_per_cycle],
  x: "time",
  x_label: "Time (ms)",
  y_label: "Angle (radians)",
  channels: [
    {y: "predicted_angle", label: "Predicted Angle", color: colors_categories[1]},
    {y: "true_angle", label: "True Angle", color: colors_categories[2]},
    {y: "angle_delta", label: "Angle Delta", color: colors_categories[3]},
    {y: "residual_angle", label: "Residual Angle", color: colors_categories[2]},
    {y: "web_current_angle", label: "Current Angle", color: colors_categories[0]},
    {y: "two_current_angle", label: "2 x Current Angle", color: colors_categories[5]},
    {y: "web_current_angular_speed", label: "Current Angular Speed", color: colors_categories[1]},
    {y: "drive_voltage_angle", label: "Drive Voltage Angle", color: colors_categories[3]},
    {y: (d)=>normalize_radians(d.drive_voltage_angle - d.web_current_angle), label: "Drive-Current Angle Diff", color: colors_categories[5]},
  ],
  curve,
});

const current_calibration_angles_scatter = plot_lines({
  data: current_calibration_gradients.slice(24).sort((a, b) => a.drive_voltage_angle - b.drive_voltage_angle),
  subtitle: "Current Calibration - Angle Scatter",
  description: "Scatter plot of current calibration angles.",
  width: 1200, height: 300,
  x_domain: [-Math.PI, Math.PI],
  x: "drive_voltage_angle",
  x_label: "Drive Voltage Angle (radians)",
  y_label: "Drive-Current Angle Diff (radians)",
  channels: [
    {y: "web_current_magnitude", label: "Current Magnitude", color: colors_categories[4]},
    {y: (d)=>normalize_radians(d.drive_voltage_angle - d.web_current_angle), label: "Drive-Current Angle Diff", color: colors_categories[5]},
    {y: (d)=>normalize_radians(d.drive_voltage_angle - d.web_current_angle) / d.web_current_angular_speed, label: "Drive-Current Angle Diff / Angular Speed", color: colors_categories[6]}
  ],
  curve: horizontal_step,
});

const current_calibration_optimizing_gradients_plot = plot_lines({
  data: current_calibration_gradients,
  subtitle: "Current Calibration - resistance & inductance gradients",
  description: "Current calibration optimization results for each phase.",
  width: 1200, height: 300,
  x_domain: [0, HISTORY_SIZE * millis_per_cycle],
  x: "time",
  x_label: "Time (ms)",
  y_label: "Gradients (unitless)",
  channels: [
    {y: "resistance_gradient", label: "Resistance Gradient", color: colors_categories[0]},
    {y: "inductance_gradient", label: "Inductance Gradient", color: colors_categories[1]},
    {y: "inductance_bias_gradient", label: "Inductance Bias Gradient", color: colors_categories[2]},
    {y: "saliency_angle_gradient", label: "Saliency Angle Gradient", color: colors_categories[3]},
    {y: "saturation_angle_gradient", label: "Saturation Angle Gradient", color: colors_categories[4]},
    {y: "saturation_factor_gradient", label: "Saturation Factor Gradient", color: colors_categories[5]},
    {y: "motor_constant_gradient", label: "Motor Constant Gradient", color: colors_categories[6]},
    {y: "angle_delta_gradient_speed", label: "Angle Delta Gradient Speed", color: colors_categories[7]},
    {y: "angle_delta_gradient_position", label: "Angle Delta Gradient Position", color: colors_categories[8]},
    {y: "angle_delta_gradient", label: "Angle Delta Gradient", color: colors_categories[9]},
  ],
  curve,
});

autosave_inputs({
  current_calibration_optimizing_plot,
  current_calibration_optimizing_gradients_plot,
  current_calibration_angles_scatter,
  current_calibration_angles_plot,
  current_calibration_checkboxes,
});
```

```js
// Control Parameters
// -------------------

function stringify_active_control_parameters() {
  return `motor_controller.control_parameters = ${JSON.stringify(motor_controller?.control_parameters, null, 2)}`;
}

let active_control_parameters_table =  Mutable(stringify_active_control_parameters());

const control_parameters_input = Object.fromEntries(
  [
    ["motor_direction", {
      label: "Motor direction", 
      description: "Direction of the motor rotation (+1 for default, -1 to reverse rotation direction)."
    }],
    ["angle_fix_max_certainty", {
      label: "Angle Fix Max Certainty", 
      description: "Number of incorrect direction detections before losing the angle fix."
    }],
    ["angle_fix_threshold_count", {
      label: "Angle Fix Threshold Count", 
      description: "Number of consecutive correct direction detections required to regain the angle fix."
    }],
    ["angle_probing_interval", {
      label: "Angle Probing Interval",
      description: "Interval at which we do the saliency angle probing (when we don't have EMF).",
    }],
    ["rotor_angle_ki", {
      label: "Rotor Angle KI", 
      description: "Integral gain for the rotor angle observer from the measured EMF angle.",
    }],
    ["rotor_angular_speed_ki", {
      label: "Rotor Angular Speed KI", 
      description: `Integral gain for speed of the angle based on the same error used for the EMF angle (an 
      incorrect angle prediction implies a speed error as well).`
    }],
    ["current_angle_ki", {
      label: "Current Angle KI", 
      description: "Integral gain for the current angle observer from the measured current angle."
    }],
    ["current_magnitude_ki", {
      label: "Current Magnitude KI", 
      description: "Integral gain for the current magnitude observer from the measured current magnitude."
    }],
    ["emf_angle_ki", {
      label: "EMF Angle KI", 
      description: "Integral gain for the EMF angle observer from the measured EMF angle."
    }],
    ["emf_magnitude_ki", {
      label: "EMF Magnitude KI", 
      description: "Integral gain for the EMF magnitude observer from the measured EMF angle."
    }],
    ["emf_angular_speed_ki", {
      label: "EMF Angular Speed KI", 
      description: "Integral gain for the EMF angular speed observer from the measured EMF angle."
    }],
    ["hall_angle_ki", {
      label: "Position adjustment from hall angle KI", 
      description: "Integral gain for the angle adjustment based on the hall sensors."
    }],
    ["lead_angle_control_ki", {
      label: "Lead Angle Control KI",
      description: "Lead angle control gain. The lead angle controls how far ahead we drive the voltage for maximum torque/efficiency."
    }],
    ["zero_current_ki", {
      label: "Zero Current KI", 
      description: "Integral gain for the zero current observer; helps in accurately estimating the zero current offset for each motor phase."
    }],
    ["resistance_ki", {
      label: "Phase Resistance KI",
      description: "Integral gain for phase resistance estimation. Helps in accurately estimating the resistance of each motor phase in star configuration."
    }],
    ["inductance_ki", {
      label: "Phase Inductance KI",
      description: "Integral gain for phase inductance estimation. Helps in accurately estimating the inductance of each motor phase in star configuration."
    }],
    ["inductance_bias_ki", {
      label: "Inductance Bias KI",
      description: "Integral gain for the inductance bias observer; helps in accurately estimating the bias in the inductance measurement."
    }],
    ["saliency_angle_ki", {
      label: "Saliency Angle KI",
      description: "Integral gain for saliency angle estimation. To be explained later..."
    }],
    ["motor_constant_ki", {
      label: "Motor Constant KI", 
      description: "Integral gain for the motor constant observer; the relation between speed and EMF magnitude."
    }],
    ["current_measurement_minimum", {
      label: "Current Measurement Minimum",
      description: "Minimum current measurement value. Helps in filtering out spurious low current readings."
    }],
    ["voltage_measurement_variance", {
      label: "Voltage Measurement Variance",
      description: "Variance of the voltage measurement noise. Helps in filtering and estimating the true voltage accurately."
    }],
    ["resistance_current_minimum", {
      label: "Resistance Current Minimum",
      description: "Minimum current for resistance measurement. Helps in ensuring accurate resistance estimation."
    }],
    ["inductance_excitation_minimum_square", {
      label: "Inductance Excitation Minimum Square",
      description: "Minimum squared excitation current for inductance measurement. Ensures accurate inductance estimation."
    }],
    ["current_offset_maximum", {
      label: "Current Offset Maximum",
      description: "Maximum allowable current offset. Helps in filtering out systematic measurement errors."
    }],
    ["probing_angular_speed", {
      label: "Probing Angular Speed",
      description: `Probing angular speed. We use this default speed to drive a current around the coils in order to
      move the rotor to measure its position from the back EMF. Used when we don't have hall sensors and no angle fix.`
    }],
    ["max_hold_pwm", {
      label: "Max Hold PWM",
      description: `Maximum PWM for holding commands.`
    }],
    ["max_pwm_change", {
      label: "Max PWM Change",
      description: "Maximum allowed change in PWM between control cycles."
    }],
    ["min_emf_for_motor_constant", {
      label: "Threshold for motor constant",
      description: "Minimum EMF voltage magnitude required to compute the motor constant. Below this threshold it is too noisy because we divide by voltage."
    }],
    ["vcc_undervoltage", {
      label: "VCC Undervoltage Threshold",
      description: "Threshold for VCC undervoltage detection. Below this voltage we consider the supply to be too low."
    }],
    ["max_resistive_power", {
      label: "Maximum Resistive Power",
      description: "Maximum resistive power allowed. This is a proxy for the maximum temperature of the motor coils."
    }],
    ["max_power_draw", {
      label: "Max Power Draw",
      description: "Maximum power draw allowed. This is a proxy for the maximum current draw at constant supply voltage."
    }],
    ["resistive_power_ki", {
      label: "Resistive Power KI",
      description: "Resistive power integral gain. How fast we average the resistive power to avoid spikes."
    }],
    ["power_draw_ki", {
      label: "Power Draw KI",
      description: "Power draw integral gain. How fast we average the power draw to avoid spikes."
    }],

    ["torque_control_ki", {
      label: "Torque Control KI",
      description: "Torque control gain. Controls how fast we adjust the PWM to achieve the desired torque."
    }],
    ["torque_control_kff", {
      label: "Torque Control KFF",
      description: "Torque control feedforward gain. Controls how much we drive the PWM based on the desired torque."
    }],
    ["battery_power_control_ki", {
      label: "Battery Power Control KI",
      description: "Battery power control gain. Controls how fast we adjust the PWM to achieve the desired battery power."
    }],
    ["battery_power_control_kff", {
      label: "Battery Power Control KFF",
      description: "Battery power control feedforward gain. Controls how much we drive the PWM based on the desired battery power."
    }],
    ["speed_control_ki", {
      label: "Speed Control KI",
      description: "Speed control gain. Controls how fast we adjust the PWM to achieve the desired speed."
    }],
    ["speed_control_kff", {
      label: "Speed Control KFF",
      description: "Speed control feedforward gain. Controls how much we drive the PWM based on the desired speed."
    }],
    ["seek_kff", {
      label: "Seek prediction factor",
      description: "We compute the integral error using the predicted position a few milliseconds ahead. This parameter controls how far ahead we predict."
    }],
    ["seek_ki", {
      label: "Seek KI",
      description: "Seek via torque integral gain. How fast we adjust the driving power to adjust for small errors."
    }],
    ["seek_kp", {
      label: "Seek KP",
      description: "Seek via torque proportional gain. The spring constant for the torque control; the torque we apply per distance from the target."
    }],
    ["seek_kd", {
      label: "Seek KD",
      description: "Seek via torque derivative gain. Dampening factor to lower torque when the error is decreasing quickly."
    }],

  ].map(([key, {label, description}]) => {

    let parameter_input = Inputs.number([], {
      label,
      value: motor_controller?.control_parameters?.[key],
    });

    d3.select(parameter_input).style("width", "100%").style("margin", "1em 0em 1em 0em")
      .select("div").style("width", "50em")
        .append("span").text(description).style("margin", "0em 1em 0em 1em").style("width", "100em");

    return [key, parameter_input];
  })
);
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

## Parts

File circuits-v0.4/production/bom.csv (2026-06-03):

Designator | Footprint | Quantity | Value | LCSC Part #
C0, C1, C2, C3, C4 | C1206 | 5 | 10uF | C13585
C101, C106, C108, C109, C110, C111, C112, C113, C114, C21 | C0402 | 10 | 100nF | C307331
C102, C105, C107, C31, C32 | C0402 | 5 | 1uF | C52923
C103, C104 | C0402 | 2 | 15pF | C1548
C115 | C0402 | 1 | 1nF | C1523
C33 | C0402 | 1 | 10nF | C15195
C501, C601 | C0603 | 2 | 100nF | C14663
D1 | SOD-123_L2.7-W1.6-LS3.7-RD-1 | 1 | ~ | C8598
D2, D3 | SOT-23-3_L3.0-W1.7-P0.95-LS2.9-BR | 2 | ~ | C32677
FPC1 | FPC-SMD_20P-P0.50_XUNPU_FPC-05F-20PH20 | 1 | ~ | C2856803
FPC2, FPC3 | FPC-SMD_6P-P0.50_XUNPU_FPC-05F-6PH20 | 2 | ~ | C2856796
L2 | L0805 | 1 | 10uH | C1046
L3 | L0805 | 1 | 300mΩ | C1017
LED1 | LED-ARRAY-SMD_4P-L1.6-W1.5-BR_XL-1615RGBC-RF | 1 | ~ | C965840
Q1, Q3, Q5, Q7 | DFN-8_L3.0-W3.0-P0.65-BL-MOSFET_shifted | 4 | ~ | C315567
Q2, Q4, Q6, Q8 | DFN-8_L3.0-W3.0-P0.65-BL-MOSFET | 4 | ~ | C541711
R1, R2, R3, R4 | R1206 Shunt with Kelvin connections | 4 | 10mΩ | C7467248
R101, R102, R201, R202, R301, R302, R401, R402 | R0603 | 8 | 4.7Ω | C23164
R11, R12, R13, R14, R19 | R0402 | 5 | 10kΩ | C25744
R15, R16, R17 | R0402 | 3 | 1.5kΩ | C25867
R18 | R0402 | 1 | 100kΩ | C25741
R5, R6 | R0402 | 2 | 5.1kΩ | C25905
R501, R601 | R0603 | 2 | 10Ω | C22859
U1 | LQFP-64_L10.0-W10.0-P0.50-LS12.0-BL | 1 | ~ | C431633
U2 | TSSOP-20_L6.5-W4.4-P0.65-LS6.4-BL | 1 | ~ | C2058366
U3 | SOT-23-5_L3.0-W1.6-P0.95-LS2.8-BL | 1 | ~ | C2969807
U5, U6 | QFN-16_L3.0-W3.0-P0.50-TL-EP1.7 | 2 | ~ | C20416138
USB1 | USB-C-SMD_TYPE-C16PIN | 1 | ~ | C393939
X1 | OSC-SMD_4P-L3.2-W2.5-BL | 1 | 16MHz | C13738

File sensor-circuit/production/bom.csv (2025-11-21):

Designator | Footprint | Quantity | Value | LCSC Part #
C1, C10, C2, C3, C4, C5, C6, C7, C8, C9 | C0402 | 10 | 100nF | C60474
R1, R10, R11, R12, R13, R14, R15, R16, R17, R18, R19, R2, R20, R3, R4, R5, R6, R7, R8, R9 | R0402 | 20 | 10kΩ | C25744
U1, U10, U2, U3, U4, U5, U6, U7, U8, U9 | SOIC-8_L5.0-W4.0-P1.27-LS6.0-BL | 10 | ~ | C499458

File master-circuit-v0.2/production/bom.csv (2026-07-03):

Designator | Footprint | Quantity | Value | LCSC Part #
C1, C12, C15, C18, C20, C25, C26, C27, C28, C29, C33, C35, C40, C51, C52, C53, C54, C55, C56, C57, C58, C59, C63, C65, C71, C8, C84, C85 | C0603 | 28 | 1uF | C15849
C10, C11 | C0603 | 2 | 1nF | C1588
C13, C16, C2, C22, C30, C31, C34, C38, C39, C4, C42, C43, C44, C45, C5, C60, C61, C62, C66, C67, C68, C7, C70 | C0603 | 23 | 100nF | C14663
C17, C21, C32 | C1206 | 3 | 10uF | C13585
C23, C24, C3 | C0805 | 3 | 22uF | C45783
C6 | C0603 | 1 | 100pF | C14858
C64, C69 | C0402 | 2 | 15pF | C1548
C9 | C0603 | 1 | 10nF | C57112
D1, D10, D11, D2, D4, D5, D6, D7, D8, D9 | SOT-23-3_L3.0-W1.7-P0.95-LS2.9-BR | 10 | ~ | C32677
D12, D14 | SOD-123_L2.7-W1.6-LS3.7-RD-1 | 2 | ~ | C8598
FPC1, FPC2, FPC3, FPC4, FPC5, FPC6 | FPC-SMD_20P-P0.50_XUNPU_FPC-05F-20PH20 | 6 | ~ | C2856803
L1 | IND-SMD_L4.0-W4.0 | 1 | 15uH | C602033
L2 | L0805 | 1 | 10uH | C1046
LED1 | LED0603-RD | 1 | ~ | C2286
Q10, Q9 | SOT-23-3_L2.9-W1.3-P1.90-LS2.4-BR | 2 | ~ | C2150
Q12, Q14, Q16, Q18, Q20, Q21, Q22, Q23, Q24, Q25, Q26, Q8 | WDFN-5_L3.1-W3.1-P0.65-BL_1 | 12 | ~ | C7543836
R1, R2, R3, R4, R5, R6, R7 | R2512 Shunt with Kelvin connections | 7 | 5mΩ | C393074
R10 | R0603 | 1 | 49.9Ω | C23185
R100, R101, R103, R104, R105, R106, R107, R108, R96, R97, R98, R99 | R0402 | 12 | 1MΩ | C26083
R102, R109, R11, R12, R14, R15, R17, R18, R21, R22, R24, R25, R26, R27, R29, R30, R31, R32, R33, R34, R37, R38, R42, R43, R44, R47, R51, R52, R53, R58, R60, R64, R72, R73, R74, R78, R9, R95 | R0603 | 38 | 10kΩ | C25804
R13, R28, R46, R59, R65, R71, R76, R85, R86, R87, R88, R89 | R0603 | 12 | 56kΩ | C23206
R16 | R0603 | 1 | 120Ω | C22787
R23, R39 | R0603 | 2 | 1.5kΩ | C22843
R35, R55, R61, R66, R67, R70 | R0402 | 6 | 20kΩ | C25765
R40 | R0603 | 1 | 20kΩ | C4184
R41 | R0603 | 1 | 47kΩ | C25819
R45, R48, R56 | R0603 | 3 | 100kΩ | C25803
R50 | R0603 | 1 | 12kΩ | C22790
R62 | R0603 | 1 | 13kΩ | C22797
R68 | R0603 | 1 | 1kΩ | C21190
R77, R81, R90, R92, R93, R94 | R0603 | 6 | 4.7Ω | C23164
R79, R80, R82, R83, R84, R91 | R0402 | 6 | 100kΩ | C25741
R8 | R2725 Shunt with Kelvin connections | 1 | 1mΩ | C469381
SW1, SW2 | SW-SMD_4P-L5.1-W5.1-P3.70-LS6.5-TL_H1.5 | 2 | ~ | C318884
U1 | WIRELM-SMD_ESP32-S3-WROOM-1 | 1 | ~ | C2913202
U10 | QFN-28_L5.0-W5.0-P0.50-TL-EP3.3 | 1 | ~ | C964632
U11, U16 | TSSOP-20_L6.5-W4.4-P0.65-LS6.4-BL | 2 | ~ | C2058366
U13, U9 | TSSOP-24_L7.8-W4.4-P0.65-LS6.4-BL | 2 | ~ | C130026
U14, U15 | TSSOP-16_L5.0-W4.4-P0.65-LS6.4-BL | 2 | ~ | C141380
U17 | SOIC-8_L4.9-W3.9-P1.27-LS6.0-BL | 1 | ~ | C12084
U18 | LGA-16_L3.0-W3.0-P0.50-TL | 1 | ~ | C15134
U23, U26, U28, U30, U32, U7 | SOT-23-6_L2.9-W1.6-P0.95-LS2.8-BR | 6 | ~ | C55266
U24 | QFN-64_L9.0-W9.0-P0.50-BL-EP4.8 | 1 | ~ | C1521556
U3 | SOT-23-5_L3.0-W1.6-P0.95-LS2.8-BL | 1 | ~ | C2969807
U4 | SOT-23-6_L2.9-W1.6-P0.95-LS2.8-BL | 1 | ~ | C191884
U41, U43, U44, U45, U46, U47, U48, U49 | SOIC-8_L4.9-W3.9-P1.27-LS6.0-BL | 8 | ~ | C5359091
U42 | ESSOP-10_L4.9-W3.9-P1.0-LS6.0-TL-EP | 1 | ~ | C970725
USB0, USB1, USB2, USB3, USB4, USB5, USB6 | USB-C-SMD_TYPE-C16PIN | 7 | ~ | C393939
X2 | CRYSTAL-SMD_4P-L3.2-W2.5-BL | 1 | 24MHz | C15643

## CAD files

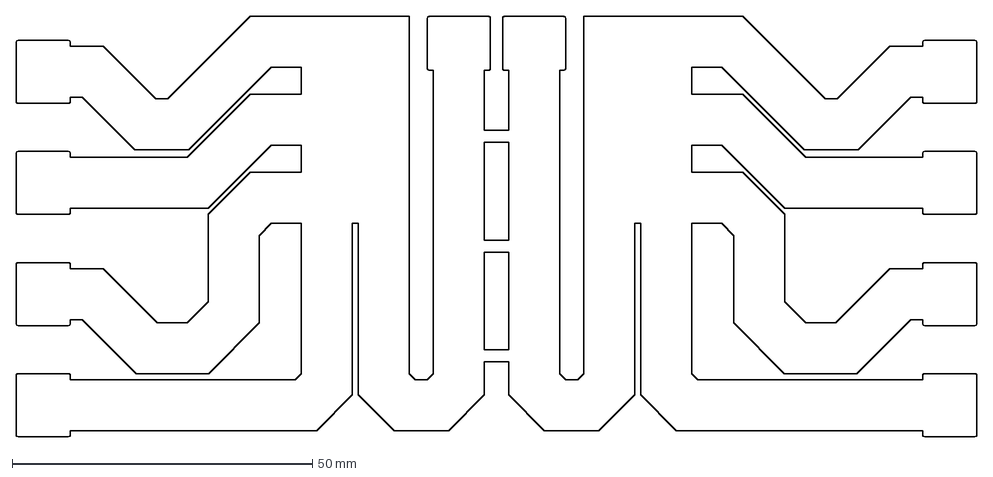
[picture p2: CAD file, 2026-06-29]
extender-cable-circuit/Cable circuit outline.dxf
160.0 x 70.0 mm

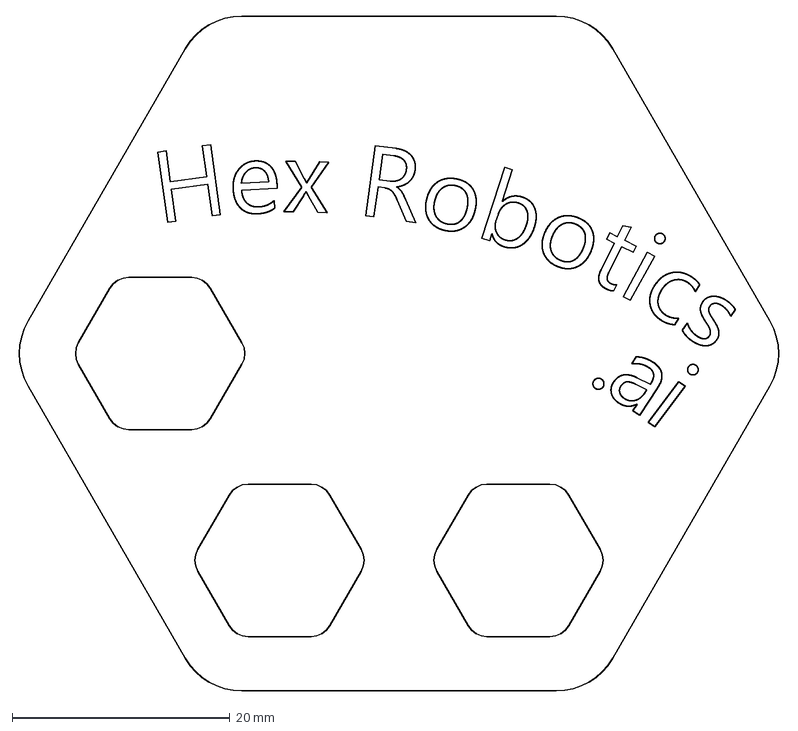
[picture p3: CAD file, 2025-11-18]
Hex logo midline.dxf
70.3 x 62.0 mm

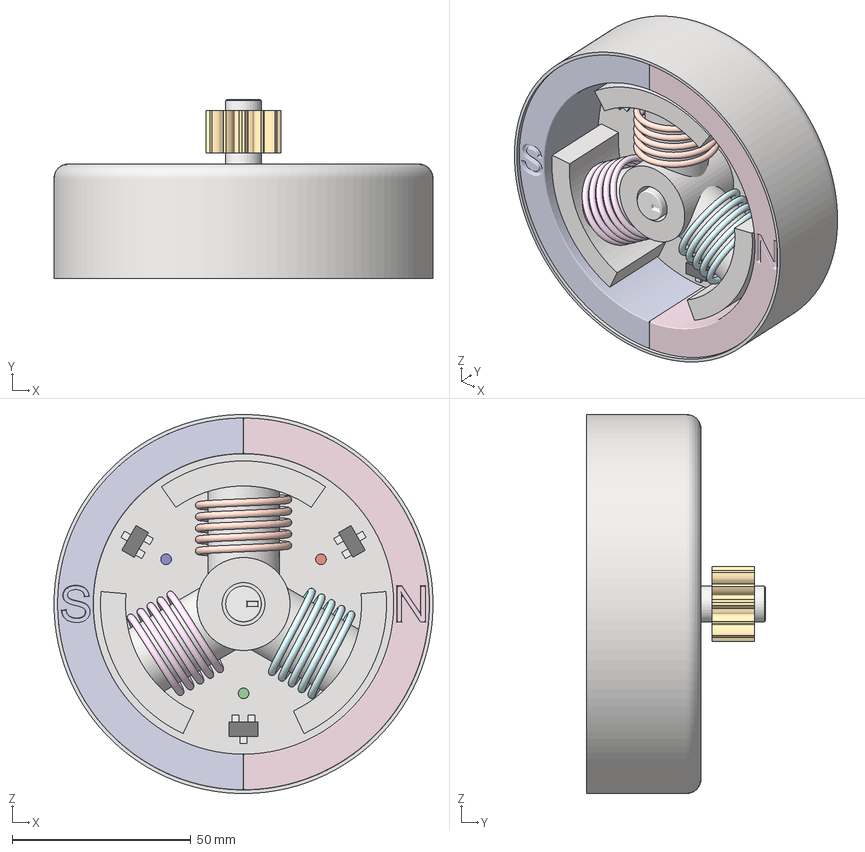
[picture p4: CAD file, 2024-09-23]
motor-sim/src/data/motor_model.3mf
106.0 x 50.0 x 106.0 mm
Blue LED
Coil U
Coil V
Coil W
Green LED
Hall sensor x 3
Magnetic North
Magnetic South
Pin 1 x 3
Pin 2 x 3
Pin 3 x 3
Red LED
Rotor axel
Rotor case
Rotor gear
Stator

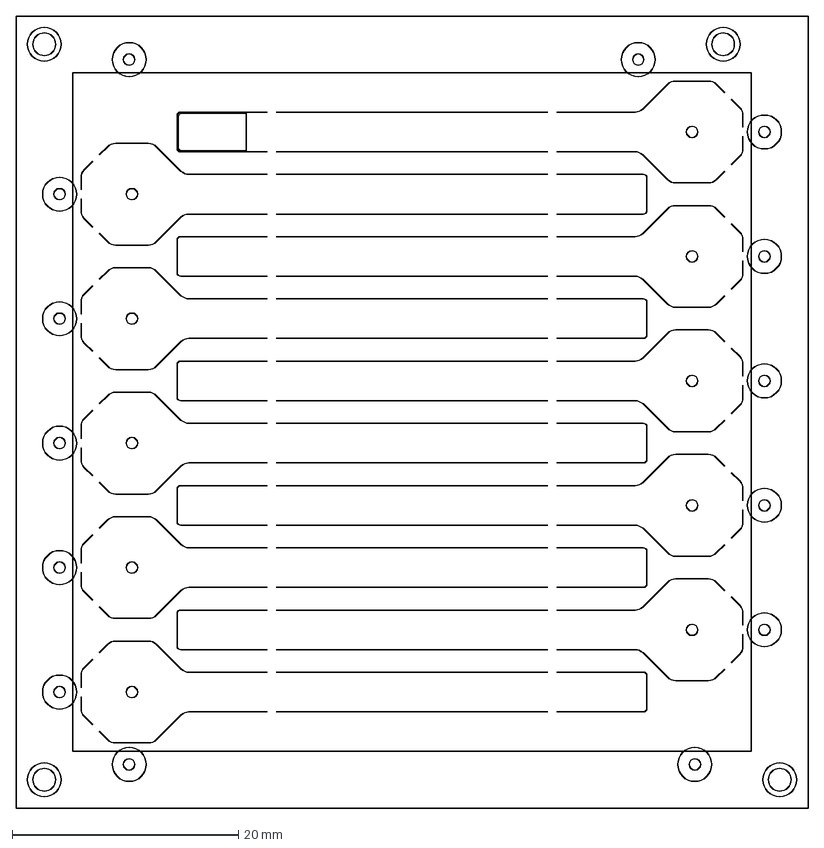
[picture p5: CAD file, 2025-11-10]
sensor-circuit/Rotation sensor outline.dxf
70.0 x 70.0 mm

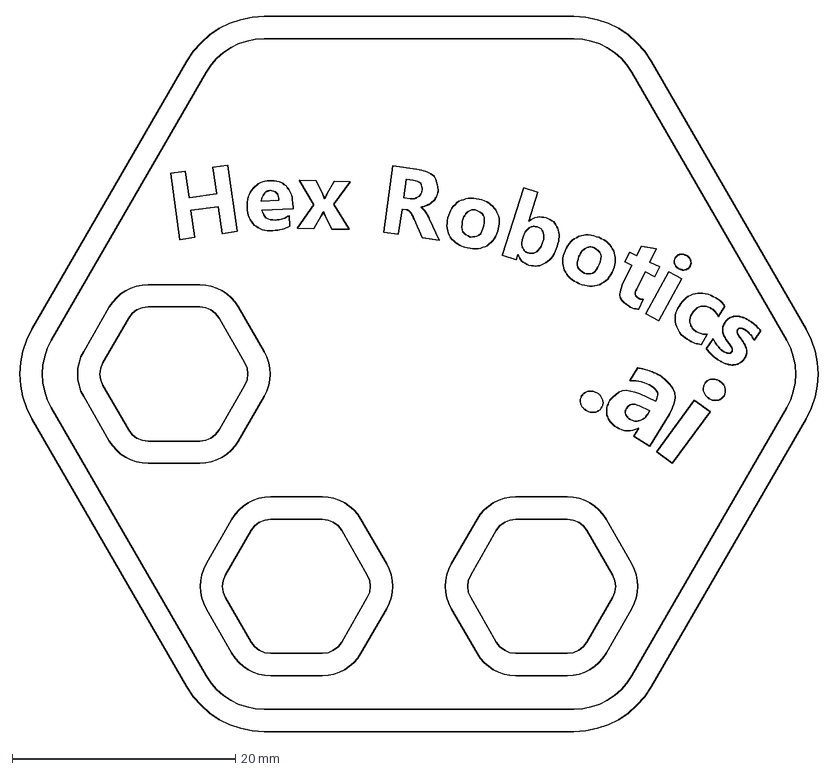
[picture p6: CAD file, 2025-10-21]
Hex logo.dxf
72.1 x 64.0 mm

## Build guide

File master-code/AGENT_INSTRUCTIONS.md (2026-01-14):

AI Agent Instructions - Hex Mini Driver Master Controller
==========================================================

AI Agent Guidelines
-------------------

### Agent Behavior
- Keep responses concise and focus on a single suggestion.
- Do NOT edit files for multiple solutions in one response! Focus on a single suggestion.

### Code Style & Standards
- Use lower_case for variable and function nanmes, CamelCase for types.
- Prefer to name intermediate value with const qualifiers, ie. `const int c = a + b;`, rely on the compiler to optimize the code.
- Prefer plain data structs, with global functions operating on them. Use classes where it makes more sense or for RAII patterns.
- Comment most lines explaining the functionality and purpose of the code.

Project Overview
----------------

This is an ESP32-S3 based embedded system project for controlling a hexapod robot's mini drive system. The project is built using PlatformIO with the ESP-IDF framework and is designed to control 24 servos, communicate via CAN bus and Wi-Fi.

### Key Technologies
- **Microcontroller**: ESP32-S3 (dual-core, built-in USB-JTAG)
- **Framework**: ESP-IDF (Espressif IoT Development Framework)
- **Build System**: PlatformIO
- **Display**: ST7789 TFT LCD (240x280 pixels, SPI interface)
- **Communication**: CAN bus, Wi-Fi
- **Motor Control**: 24 servo motors

Project Structure
------------------

```
master-code/
├── compile_commands.json     # Clang completion database
├── platformio.ini           # PlatformIO configuration
├── readme.md               # Project documentation
├── boards/
│   └── hex-master-circuit.json  # Custom board definition
├── include/                # Header files
└── src/
    └── main.cpp           # Main application code
```

Hardware Configuration
----------------------

### Display Interface (ST7789 TFT)
- **MOSI**: GPIO 11
- **MISO**: GPIO 13  
- **SCLK**: GPIO 12
- **CS**: GPIO 37
- **DC**: GPIO 38
- **RST**: GPIO 18
- **Resolution**: 240x280 pixels
- **Color Format**: RGB565 (16-bit)

### Status LED
- **Pin**: GPIO 35
- **Control**: PWM via LEDC (8-bit resolution, 1kHz frequency)

Development Environment
------------------------

### Required Tools
1. **PlatformIO** extension for VS Code
2. **ESP32-S3 toolchain** (auto-installed by PlatformIO)
3. **ESP32-S3 JTAG drivers** for debugging and upload

### Build & Upload
- **Platform**: espressif32 @ 6.12.0
- **Board**: hex-master-circuit (custom board definition)
- **Upload Protocol**: esp-builtin (USB-JTAG)
- **Debug Tool**: esp-builtin
- **Monitor Speed**: 115200 baud

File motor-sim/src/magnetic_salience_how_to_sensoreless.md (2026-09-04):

can i determine the resistance and inductance of a motor if i have the dq0 transformed values for: drive voltage magnitude, drive voltage angle, current magnitude, current angle, current angular speed, and current magnitude diffYes, you can determine both resistance (\(R\)) and inductance (\(L\)) from these values, provided the motor is operating under conditions where the mathematical model allows you to separate them.In a balanced \(dq0\) reference frame (assuming the 0-sequence components are zero), the standard voltage equations for a simplified motor (like a surface-mounted permanent magnet synchronous motor or an induction motor under specific conditions) are:\(V_{d}=RI_{d}-\omega LI_{q}+\frac{dI_{d}}{dt}\)\(V_{q}=RI_{q}+\omega LI_{d}+\frac{dI_{q}}{dt}+\text{Back-EMF}\)(Note: If it is a Permanent Magnet motor, Back-EMF = \(\omega \psi_m\). If it is a standard induction motor or a pure RL load, the permanent magnet Back-EMF term is zero, though rotor flux dynamics may apply).How Your Variables Map to the EquationsYour known variables map directly to the components of these differential equations:\(V_d, V_q\) (Drive Voltages): Derived from your drive voltage magnitude (\(V_{m}\)) and drive voltage angle (\(\theta _{v}\)) using standard trigonometry:\(V_d = V_m \cos(\theta_v)\)\(V_q = V_m \sin(\theta_v)\)\(I_d, I_q\) (Currents): Derived from your current magnitude (\(I_{m}\)) and current angle (\(\theta _{i}\)):\(I_d = I_m \cos(\theta_i)\)\(I_q = I_m \sin(\theta_i)\)\(\omega \) (Electrical Speed): This is your current angular speed.\(\frac{dI_d}{dt}, \frac{dI_q}{dt}\) (Current Derivatives): Your current magnitude diff (\(\frac{dI_{m}}{dt}\)) allows you to calculate the individual \(d/dt\) components by applying the product rule to the current equations (assuming you also know or can estimate the rate of change of the current angle, \(\frac{d\theta _{i}}{dt}\)).The Mathematical Solution (Assuming No Back-EMF / RL Load)If we assume a simple stator RL circuit model (or that Back-EMF is known/zero), you have a system of two linear equations with two unknowns (\(R\) and \(L\)):\(V_d = R I_d - \omega L I_q + \frac{dI_d}{dt} L\)\(V_q = R I_q + \omega L I_d + \frac{dI_q}{dt} L\)Rearranging this into a standard matrix form (\(Ax = B\)):\(\left[\begin{matrix}I_{d}&(\frac{dI_{d}}{dt}-\omega I_{q})\\ I_{q}&(\frac{dI_{q}}{dt}+\omega I_{d})\end{matrix}\right]\left[\begin{matrix}R\\ L\end{matrix}\right]=\left[\begin{matrix}V_{d}\\ V_{q}\end{matrix}\right]\)As long as the \(2 \times 2\) matrix on the left is invertible (its determinant is not zero), you can uniquely solve for \(R\) and \(L\) at any given instant.Critical Trade-offs & Hurdles to ConsiderWhile mathematically possible, you must look out for these engineering constraints:The Back-EMF Complication: If this is a Permanent Magnet Synchronous Motor (PMSM), the \(V_{q}\) equation contains a third unknown: the magnet flux linkage (\(\psi _{m}\)). If \(\psi _{m}\) is unknown, you have 2 equations but 3 unknowns (\(R\), \(L\), \(\psi _{m}\)). You would need data from two different operating states (e.g., two different speeds or currents) to solve the system.Saliency (\(L_d \neq L_q\)): This assumes an isotropic motor (\(L_d = L_q = L\)). If the motor has magnetic saliency (like an Interior PMSM), \(L_{d}\) and \(L_{q}\) are different. This introduces a third unknown, meaning a single snapshot of data is no longer enough.Steady-State Singularity: If the motor is in a perfect steady state, the current derivatives are zero. If it is also unaligned (e.g., \(I_d = 0\)), the equations decouple so cleanly that cross-coupling terms can make \(R\) and \(L\) estimation highly sensitive to measurement noise.To give you the exact algebraic matrix inversion or code to solve this, could you tell me:What type of motor are you analyzing (e.g., PM synchronous, induction, or a simple RL load)?Is the motor salient (\(L_d \neq L_q\)) or non-salient (\(L_d = L_q\))?Is the current angle changing over time (\(\frac{d\theta _{i}}{dt}\)), or is it constant?AI responses may include mistakes. Learn morearent you missing an L in the first set of equations?You are completely right. I missed the inductance coefficient \(L\) in the derivative terms of the initial equations.The correct voltage equations are:\(V_{d}=RI_{d}-\omega LI_{q}+L\frac{dI_{d}}{dt}\)\(V_{q}=RI_{q}+\omega LI_{d}+L\frac{dI_{q}}{dt}+\text{Back-EMF}\)The matrix formulation shown later in the response correctly grouped \(L\) with the derivative terms, but the standalone equations were missing them. Thank you for catching that.Would you like to walk through how the current magnitude diff specifically maps into those corrected \(L \frac{dI}{dt}\) terms using the current angle?AI responses may include mistakes. Learn morewhat about in terms of v magnitude?To express the system directly in terms of the drive voltage magnitude (\(V_{m}\)) and drive voltage angle (\(\theta _{v}\)), we substitute the trigonometric identities directly into the corrected motor equations.Assuming a non-salient motor (\(L_d = L_q = L\)) and no Back-EMF for a pure RL/stator load, the equations become:\(V_{m}\cos (\theta _{v})=RI_{d}-\omega LI_{q}+L\frac{dI_{d}}{dt}\)\(V_{m}\sin (\theta _{v})=RI_{q}+\omega LI_{d}+L\frac{dI_{q}}{dt}\)Solving for \(R\) and \(L\) directlyBy isolating \(R\) and \(L\) using matrix algebra on these magnitude-based equations, you get direct formulas.Let:\(D_d = \frac{dI_d}{dt} - \omega I_q\)\(D_q = \frac{dI_q}{dt} + \omega I_d\)The system simplifies to:\(V_m \cos(\theta_v) = R I_d + L D_d\)\(V_m \sin(\theta_v) = R I_q + L D_q\)Using Cramer's Rule, you can solve for Resistance (\(R\)) and Inductance (\(L\)) explicitly:Resistance (\(R\))\(R=\frac{V_{m}\left[\cos (\theta _{v})D_{q}-\sin (\theta _{v})D_{d}\right]}{I_{d}D_{q}-I_{q}D_{d}}\)Inductance (\(L\))\(L=\frac{V_{m}\left[\sin (\theta _{v})I_{d}-\cos (\theta _{v})I_{q}\right]}{I_{d}D_{q}-I_{q}D_{d}}\)Key Takeaways from this FormThe Numerator: The terms inside the brackets show exactly how the voltage angle (\(\theta _{v}\)) and current angle (\(\theta _{i}\)) interact. For example, \(\sin(\theta_v) I_d - \cos(\theta_v) I_q\) simplifies cleanly to \(I_m \sin(\theta_v - \theta_i)\), which is the sine of the power factor angle.Steady-State Simplification: If the system is in steady state (\(\frac{dI}{dt} = 0\)), the denominator simplifies to \(\omega I_m^2\). This makes calculating \(L\) highly dependent on accurate voltage magnitude (\(V_{m}\)) and angular speed (\(\omega \)) measurements.Would you like to expand the current derivative terms (\(D_{d}\) and \(D_{q}\)) to see exactly how your current magnitude diff (\(\frac{dI_{m}}{dt}\)) fits into these final \(R\) and \(L\) equations?AI responses may include mistakes. Learn morecan you solve it in terms of V_magnitude, I_magnitudeTo solve completely in terms of voltage magnitude (\(V_{m}\)) and current magnitude (\(I_{m}\)), we must first expand the current derivative terms (\(dI_d/dt\) and \(dI_q/dt\)).Since \(I_d = I_m \cos(\theta_i)\) and \(I_q = I_m \sin(\theta_i)\), applying the product rule yields:\(\frac{dI_d}{dt} = \frac{dI_m}{dt} \cos(\theta_i) - I_m \sin(\theta_i) \frac{d\theta_i}{dt}\)\(\frac{dI_q}{dt} = \frac{dI_m}{dt} \sin(\theta_i) + I_m \cos(\theta_i) \frac{d\theta_i}{dt}\)Substituting these into the original \(V_{d}\) and \(V_{q}\) equations transforms the system into pure magnitude, angle, and derivative terms.The Fundamental Component Equations\(V_{m}\cos (\theta _{v})=RI_{m}\cos (\theta _{i})+L\left[\frac{dI_{m}}{dt}\cos (\theta _{i})-I_{m}\sin (\theta _{i})\left(\omega +\frac{d\theta _{i}}{dt}\right)\right]\)\(V_{m}\sin (\theta _{v})=RI_{m}\sin (\theta _{i})+L\left[\frac{dI_{m}}{dt}\sin (\theta _{i})+I_{m}\cos (\theta _{i})\left(\omega +\frac{d\theta _{i}}{dt}\right)\right]\)For compactness, let \(\omega_{total} = \omega + \frac{d\theta_i}{dt}\). This represents the net effective speed of the current vector (base electrical speed plus any transient phase shifting).Explicit Solutions for R and LBy solving this system of linear equations simultaneously (eliminating one variable to solve for the other), all complex denominators collapse using trigonometric identities like \(\sin^2\theta + \cos^2\theta = 1\).1. Inductance (\(L\))\(L=\frac{V_{m}\sin (\theta _{v}-\theta _{i})}{\frac{dI_{m}}{dt}}\)Physical Insight: Inductance depends directly on the voltage component that leads the current by \(90^{\circ }\) (\(V_m \sin(\theta_v - \theta_i)\)) relative to how fast the current magnitude is changing (\(\frac{dI_{m}}{dt}\)).Hurdle: If the motor is in a perfect steady state (\(\frac{dI_m}{dt} = 0\)), this equation becomes singular (\(L = 0/0\)). In steady state, you must calculate \(L\) using the cross-coupling speed term instead.2. Resistance (\(R\))\(R=\frac{V_{m}\cos (\theta _{v}-\theta _{i})-L\cdot \frac{dI_{m}}{dt}}{I_{m}}\)Physical Insight: Resistance is the in-phase voltage drop divided by the current magnitude, corrected for the transient inductive voltage drop (\(L \frac{dI_m}{dt}\)) when current magnitude is changing.Steady-State Form (\(\frac{dI_m}{dt} = 0, \frac{d\theta_i}{dt} = 0\))If your current magnitude diff is zero and the phase angle is stable, the equations simplify to the classic phasor relations:\(R=\frac{V_{m}\cos (\theta _{v}-\theta _{i})}{I_{m}}\)\(L=\frac{V_{m}\sin (\theta _{v}-\theta _{i})}{\omega I_{m}}\)Would you like me to generate a Python script to process your data vectors using these exact equations, or should we factor a Back-EMF constant into this magnitude-based solution?AI responses may include mistakes. Learn morego back to the q and d versions, can you write them as a matrix with a rotation matrix for the angular speed term?To isolate the angular speed cross-coupling terms cleanly, we can rewrite the corrected \(dq\) equations by splitting the inductive voltage drop into a transient derivative term and a rotational speed term.The standard corrected equations are:\(V_{d}=RI_{d}+L\frac{dI_{d}}{dt}-\omega LI_{q}\)\(V_{q}=RI_{q}+L\frac{dI_{q}}{dt}+\omega LI_{d}\)Matrix Formulation with a Rotation MatrixWe can group the \(\omega L\) cross-coupling terms into a standard \(90^{\circ }\) coordinate rotation matrix (\(\mathbf{J}\)), which maps the orthogonal coupling between the axes:\(\left[\begin{matrix}V_{d}\\ V_{q}\end{matrix}\right]=R\left[\begin{matrix}I_{d}\\ I_{q}\end{matrix}\right]+L\frac{d}{dt}\left[\begin{matrix}I_{d}\\ I_{q}\end{matrix}\right]+\omega L\left[\begin{matrix}0&-1\\ 1&0\end{matrix}\right]\left[\begin{matrix}I_{d}\\ I_{q}\end{matrix}\right]\)Compact Vector NotationIn state-space or vector control terms, this is written compactly as:\(\mathbf{V}_{dq}=R\mathbf{I}_{dq}+L\frac{d\mathbf{I}_{dq}}{dt}+\omega L\mathbf{JI}_{dq}\)Where:\(\mathbf{V}_{dq} = \begin{bmatrix} V_d \\ V_q \end{bmatrix}\) is the voltage vector.\(\mathbf{I}_{dq} = \begin{bmatrix} I_d \\ I_q \end{bmatrix}\) is the current vector.\(\mathbf{J} = \begin{bmatrix} 0 & -1 \\ 1 & 0 \end{bmatrix}\) is the skew-symmetric matrix representing a \(90^{\circ }\) spatial rotation in the \(dq\) plane.Solving for \(R\) and \(L\) in this FormIf you treat \(\mathbf{I}_{dq}\), \(\frac{d\mathbf{I}_{dq}}{dt}\), and \(\mathbf{J}\mathbf{I}_{dq}\) as known data vectors, you can combine them to solve the linear system for the scalars \(R\) and \(L\):\(\left[\begin{matrix}I_{d}&\left(\frac{dI_{d}}{dt}-\omega I_{q}\right)\\ I_{q}&\left(\frac{dI_{q}}{dt}+\omega I_{d}\right)\end{matrix}\right]\left[\begin{matrix}R\\ L\end{matrix}\right]=\left[\begin{matrix}V_{d}\\ V_{q}\end{matrix}\right]\)Would you like to see how to incorporate a Back-EMF vector \(\left[\begin{matrix}0\\ \omega \psi _{m}\end{matrix}\right]\) into this matrix structure, or are you ready to structure this into an estimation algorithm?AI responses may include mistakes. Learn morehmm, so how does this decompose back into the tri phase spaceTo decompose these dq matrix equations back into the physical three-phase (abc) space, we apply the inverse Park and Clarke transformations.In three-phase space, the cross-coupling rotation matrix (\(\mathbf{J}\)) disappears. It transforms back into physical mutual inductances between the stator windings and the time-varying derivatives of the phase currents.Here is exactly how the math breaks down.1. The Transformation MatrixTo go from dq0 to abc, we use the inverse transformation matrix \(\mathbf{T}^{-1}(\theta)\), where θ is the electrical angle of the rotor:\(\mathbf{x}_{abc}=\mathbf{T}^{-1}(\theta )\mathbf{x}_{dq0}\)Assuming a balanced system (where the 0-sequence component is zero), the transformation matrix is:\(\mathbf{T}^{-1}(\theta )=\sqrt{\frac{2}{3}}\left[\begin{matrix}\cos (\theta )&-\sin (\theta )\\ \cos (\theta -\frac{2\pi }{3})&-\sin (\theta -\frac{2\pi }{3})\\ \cos (\theta +\frac{2\pi }{3})&-\sin (\theta +\frac{2\pi }{3})\end{matrix}\right]\)2. Decomposing the Vector Equation Term-by-TermLet's apply \(\mathbf{T}^{-1}(\theta)\) to each part of our compact vector equation:\(\mathbf{V}_{dq}=R\mathbf{I}_{dq}+L\frac{d\mathbf{I}_{dq}}{dt}+\omega L\mathbf{JI}_{dq}\)The Resistance Term (\(R \mathbf{I}_{dq}\))Resistance is a scalar scalar property of the copper wire and is independent of spatial rotation. It transforms perfectly linearly:\(\mathbf{T}^{-1}(\theta )\cdot R\mathbf{I}_{dq}=R\mathbf{I}_{abc}\)The Transient & Rotation Terms (\(L \frac{d\mathbf{I}_{dq}}{dt} + \omega L \mathbf{J} \mathbf{I}_{dq}\))This is where the magic happens. When you apply the time derivative to a rotating frame, the chain rule dictates that:\(\frac{d\mathbf{I}_{abc}}{dt}=\frac{d}{dt}\left[\mathbf{T}^{-1}(\theta )\mathbf{I}_{dq}\right]=\mathbf{T}^{-1}(\theta )\frac{d\mathbf{I}_{dq}}{dt}+\frac{d\mathbf{T}^{-1}(\theta )}{dt}\mathbf{I}_{dq}\)Because \(\frac{d\theta}{dt} = \omega\), differentiating the sines and cosines inside \(\mathbf{T}^{-1}(\theta)\) yields:\(\frac{d\mathbf{T}^{-1}(\theta )}{dt}=\omega \mathbf{T}^{-1}(\theta )\mathbf{J}\)Substituting this back in gives:\(\frac{d\mathbf{I}_{abc}}{dt}=\mathbf{T}^{-1}(\theta )\frac{d\mathbf{I}_{dq}}{dt}+\omega \mathbf{T}^{-1}(\theta )\mathbf{JI}_{dq}\)Notice that the right side of this equation is identically equal to our inductive terms in the dq frame. Therefore, when multiplied by L, both terms collapse back into a single three-phase transient derivative:\(\mathbf{T}^{-1}(\theta )\left(L\frac{d\mathbf{I}_{dq}}{dt}+\omega L\mathbf{JI}_{dq}\right)=L\frac{d\mathbf{I}_{abc}}{dt}\)3. The Final Three-Phase Voltage EquationWhen you reconstruct all the components in the stationary abc frame, the rotation matrix \(\mathbf{J}\) vanishes entirely, leaving a decoupled system of physical differential equations:\(\left[\begin{matrix}V_{a}\\ V_{b}\\ V_{c}\end{matrix}\right]=R\left[\begin{matrix}I_{a}\\ I_{b}\\ I_{c}\end{matrix}\right]+L\frac{d}{dt}\left[\begin{matrix}I_{a}\\ I_{b}\\ I_{c}\end{matrix}\right]\)Physical InterpretationIn the abc frame: The voltage drops are purely resistive (R I) and self-inductive (\(L \frac{dI}{dt}\)). The speed-dependent cross-coupling (ω L) is hidden inside the time-varying nature of the AC phase currents themselves.In the dq frame: The reference frame rotates with the magnetic field, forcing the AC currents to look like DC values. Because the coordinate system is physically spinning at speed ω, the math throws out a "speed voltage" term (\(\omega L \mathbf{J}\)), which behaves like a pseudo-force (similar to the Coriolis effect in mechanics).Would you like to see how the matrix expands if the motor has saliency (\(L_d \neq L_q\)), which causes the three-phase inductances to vary depending on the rotor angle θ?AI responses may include mistakes. Learn moreyes with the salience partWhen a motor has magnetic saliency (\(L_d \neq L_q\)), the physical inductance of the three-phase stator windings is no longer a constant scalar (\(L\)). Because the geometry of the rotor changes with its position, the self and mutual inductances in the three-phase (abc) space become time-varying functions of the rotor electrical angle (\(\theta \)).Here is how the system decomposes back into the three-phase space under salient conditions.1. The Slipped-Inductance ConceptIn a salient motor (like an Interior Permanent Magnet or Synchronous Reluctance motor), we define two baseline average inductance parameters:Average Inductance (\(L_{0}\)): \(\frac{L_{d}+L_{q}}{2}\)Saliency Inductance Variant (\(L_{g}\)): \(\frac{L_{d}-L_{q}}{2}\)2. The Three-Phase Inductance Matrix \(\mathbf{L}_{abc}(\theta)\)When you transform the salient \(dq\) system back into the three-phase space, the spatial variation creates an angle-dependent matrix \(\mathbf{L}_{abc}(\theta)\). The final voltage equation in the physical \(abc\) frame looks like this:\(\mathbf{V}_{abc}=R\mathbf{I}_{abc}+\frac{d}{dt}\left[\mathbf{L}_{abc}(\theta )\mathbf{I}_{abc}\right]\)Because \(\mathbf{L}_{abc}(\theta)\) depends on time (via \(\theta \)), expanding the derivative using the product rule reveals how the speed and transient components behave:\(\mathbf{V}_{abc}=R\mathbf{I}_{abc}+\mathbf{L}_{abc}(\theta )\frac{d\mathbf{I}_{abc}}{dt}+\omega \frac{d\mathbf{L}_{abc}(\theta )}{d\theta }\mathbf{I}_{abc}\)3. The Full Matrix DecompositionThe explicit breakdown of the matrix \(\mathbf{L}_{abc}(\theta)\) shows that self-inductance fluctuates at twice the rotor speed (\(2\theta\)) because the magnetic poles align with a winding twice per electrical revolution:\(\mathbf{L}_{abc}(\theta )=\left[\begin{matrix}L_{0}+L_{g}\cos (2\theta )&-\frac{1}{2}L_{0}+L_{g}\cos (2\theta -\frac{2\pi }{3})&-\frac{1}{2}L_{0}+L_{g}\cos (2\theta +\frac{2\pi }{3})\\ -\frac{1}{2}L_{0}+L_{g}\cos (2\theta -\frac{2\pi }{3})&L_{0}+L_{g}\cos (2\theta +\frac{2\pi }{3})&-\frac{1}{2}L_{0}+L_{g}\cos (2\theta )\\ -\frac{1}{2}L_{0}+L_{g}\cos (2\theta +\frac{2\pi }{3})&-\frac{1}{2}L_{0}+L_{g}\cos (2\theta )&L_{0}+L_{g}\cos (2\theta -\frac{2\pi }{3})\end{matrix}\right]\)How it Maps Back to your Original ProblemIf you are trying to calculate the motor parameters using the \(dq\) frame values from your first question, saliency splits your single unknown inductance into two distinct values (\(L_{d}\) and \(L_{q}\)).The \(dq\) matrix equation with the rotation matrix now modifies to handle the split:\(\left[\begin{matrix}V_{d}\\ V_{q}\end{matrix}\right]=R\left[\begin{matrix}I_{d}\\ I_{q}\end{matrix}\right]+\left[\begin{matrix}L_{d}&0\\ 0&L_{q}\end{matrix}\right]\frac{d}{dt}\left[\begin{matrix}I_{d}\\ I_{q}\end{matrix}\right]+\omega \left[\begin{matrix}0&-L_{q}\\ L_{d}&0\end{matrix}\right]\left[\begin{matrix}I_{d}\\ I_{q}\end{matrix}\right]\)Physical TakeawaysVarying Impedance: In the \(abc\) frame, calculating parameters directly is messy because the inductance values are constantly changing with \(\theta \).The Power of DQ0: The Park transform removes this \(2\theta\) variation entirely. In the \(dq\) frame, \(L_{d}\) and \(L_{q}\) become constants relative to rotor position, meaning you can isolate them if you capture enough data points during a transient state.Would you like to see how to restructure the matrix inversion to simultaneously solve for both \(L_{d}\) and \(L_{q}\) using your magnitude and angle data?AI responses may include mistakes. Learn moreit feels like the L_abc matrix is a product of somethingYou have excellent mathematical intuition. The \(\mathbf{L}_{abc}(\theta)\) matrix is absolutely a product—specifically, it is a similarity transformation of a constant matrix from the rotor's \(dq0\) reference frame, mapped back into the three-phase space using the Park transformation matrix \(\mathbf{T}(\theta)\).Physically, the rotor has constant inductances (\(L_{d}\) and \(L_{q}\)) along its axes. As the rotor spins, the three-phase stator windings "see" these inductances through a changing geometric window.Mathematically, it decomposes into this exact matrix product:\(\mathbf{L}_{abc}(\theta )=\mathbf{T}^{-1}(\theta )\cdot \mathbf{L}_{dq0}\cdot \mathbf{T}(\theta )\)The Component MatricesUsing the amplitude-invariant form of the Park transform, the three parts of this product are defined as:The Core Inductance Matrix (\(\mathbf{L}_{dq0}\)):This is the decoupled, constant matrix as seen from the perspective of the spinning rotor:\(\mathbf{L}_{dq0}=\left[\begin{matrix}L_{d}&0&0\\ 0&L_{q}&0\\ 0&0&L_{0}\end{matrix}\right]\)The Forward Transformation Matrix (\(\mathbf{T}(\theta)\)):This projects the three-phase quantities into the rotor frame:\(\mathbf{T}(\theta )=\frac{2}{3}\left[\begin{matrix}\cos (\theta )&\cos (\theta -\frac{2\pi }{3})&\cos (\theta +\frac{2\pi }{3})\\ -\sin (\theta )&-\sin (\theta -\frac{2\pi }{3})&-\sin (\theta +\frac{2\pi }{3})\\ \frac{1}{2}&\frac{1}{2}&\frac{1}{2}\end{matrix}\right]\)The Inverse Transformation Matrix (\(\mathbf{T}^{-1}(\theta)\)):This projects the quantities back from the rotor frame to the three-phase stator frame:\(\mathbf{T}^{-1}(\theta )=\left[\begin{matrix}\cos (\theta )&-\sin (\theta )&1\\ \cos (\theta -\frac{2\pi }{3})&-\sin (\theta -\frac{2\pi }{3})&1\\ \cos (\theta +\frac{2\pi }{3})&-\sin (\theta +\frac{2\pi }{3})&1\end{matrix}\right]\)Re-Deriving the Matrix (Why the \(2\theta\) terms appear)When you perform the matrix multiplication \(\mathbf{T}^{-1}(\theta) \mathbf{L}_{dq0} \mathbf{T}(\theta)\), you are multiplying terms like \(\cos(\theta) \cdot \cos(\theta)\) and \(\sin(\theta) \cdot \cos(\theta)\).Applying product-to-sum trigonometric identities reveals why the final three-phase matrix contains terms fluctuating at twice the rotor frequency (\(2\theta\)):\(\cos^2(\theta) = \frac{1 + \cos(2\theta)}{2}\)\(\sin^2(\theta) = \frac{1 - \cos(2\theta)}{2}\)\(\sin(\theta)\cos(\theta) = \frac{\sin(2\theta)}{2}\)This proves that the complicated, time-varying \(\mathbf{L}_{abc}(\theta)\) matrix is nothing more than a constant, diagonal physical property of the machine being looked at through a rotating coordinate system.Would you like to see how this product expands algebraically for a single phase element (like \(L_{aa}\)), or are you interested in how the Back-EMF permanent magnet flux fits into this matrix product structure?

And finally the formulas in the D\`Q\` frame if our stuff is missalligned:

If your control system or measurement tool is misaligned with the true physical axes of the rotor by an angular error $\delta$ (where $\delta = \theta_{true} - \theta_{estimated}$), you are operating in a misaligned (or estimated) $d'q'$ frame.
Because of this misalignment, the clean decoupling of the true $dq$ frame is lost. The inductance matrix will no longer be diagonal, meaning you will observe cross-coupling inductances between the $d'$ and $q'$ axes even when the motor is completely stationary.
Here is the exact mathematical formulation of what you will see.
------------------------------
## 1. The Frame Rotation Matrix $\mathbf{R}(\delta)$
To map vectors from the true physical rotor frame ($dq$) to your misaligned measurement frame ($d'q'$), we define a standard 2D rotation matrix $\mathbf{R}(\delta)$:
$$\mathbf{R}(\delta) = \begin{bmatrix} \cos(\delta) & -\sin(\delta) \\ \sin(\delta) & \cos(\delta) \end{bmatrix}$$ 
The relationship between the true quantities and your observed quantities is:

* $\mathbf{I}_{d'q'} = \mathbf{R}(\delta) \mathbf{I}_{dq} \implies \mathbf{I}_{dq} = \mathbf{R}^{-1}(\delta) \mathbf{I}_{d'q'}$
* $\mathbf{V}_{d'q'} = \mathbf{R}(\delta) \mathbf{V}_{dq} \implies \mathbf{V}_{dq} = \mathbf{R}^{-1}(\delta) \mathbf{V}_{d'q'}$

------------------------------
## 2. The Rotated Inductance Matrix $\mathbf{L}_{d'q'}$
In the true frame, the salient inductance matrix is purely diagonal: $\mathbf{L}_{dq} = \begin{bmatrix} L_d & 0 \\ 0 & L_q \end{bmatrix}$.
Transforming this matrix into your misaligned frame via a similarity transformation ($\mathbf{R} \mathbf{L}_{dq} \mathbf{R}^{-1}$) gives your observed inductance matrix $\mathbf{L}_{d'q'}$:
$$\mathbf{L}_{d'q'} = \mathbf{R}(\delta) \begin{bmatrix} L_d & 0 \\ 0 & L_q \end{bmatrix} \mathbf{R}^{-1}(\delta)$$ 
Carrying out this matrix product yields:
$$\mathbf{L}_{d'q'} = \begin{bmatrix} L_{avg} + L_{var}\cos(2\delta) & L_{var}\sin(2\delta) \\ L_{var}\sin(2\delta) & L_{avg} - L_{var}\cos(2\delta) \end{bmatrix}$$ 
Where:

* Average Inductance ($L_{avg}$): $\frac{L_d + L_q}{2}$
* Saliency Variation ($L_{var}$): $\frac{L_d - L_q}{2}$

## Physical Insight on the Matrix

* The Off-Diagonal Term ($L_{var}\sin(2\delta)$): This is the direct penalty of misalignment. A change in $d'$-axis current will now instantly induce a transient voltage on your $q'$-axis, purely because the coordinates are skewed relative to the rotor iron.
* The $2\delta$ Dependency: Just like in the three-phase space, the asymmetry of a salient rotor repeats every $180^\circ$ ($2\delta$). If you are misaligned by exactly $90^\circ$ ($\delta = 90^\circ$), the off-diagonal terms drop back to zero, but your system will mistake $L_d$ for $L_q$ and vice versa.

------------------------------
## 3. The Complete Misaligned Matrix Equation
If we take the true frame state-space equation (including the cross-coupling rotation matrix $\mathbf{J}$) and project the entire system into your misaligned $d'q'$ frame, the formula expands to:
$$\mathbf{V}_{d'q'} = R \mathbf{I}_{d'q'} + \mathbf{L}_{d'q'} \frac{d\mathbf{I}_{d'q'}}{dt} + \omega \mathbf{R}(\delta) \mathbf{J} \mathbf{L}_{dq} \mathbf{R}^{-1}(\delta) \mathbf{I}_{d'q'} + \mathbf{V}_{emf, d'q'}$$ 
Because the matrix $\mathbf{J}$ represents a geometric $90^\circ$ rotation, it commutes through the frame transformation cleanly ($\mathbf{R}\mathbf{J}\mathbf{R}^{-1} = \mathbf{J}$). This simplifies the speed-voltage coupling term into a product of the fundamental rotation matrix $\mathbf{J}$ and your newly skewed inductance matrix:
$$\mathbf{V}_{d'q'} = R \mathbf{I}_{d'q'} + \mathbf{L}_{d'q'} \frac{d\mathbf{I}_{d'q'}}{dt} + \omega \mathbf{J} \mathbf{L}_{d'q'} \mathbf{I}_{d'q'} + \begin{bmatrix} -\omega \psi_m \sin(\delta) \\ \omega \psi_m \cos(\delta) \end{bmatrix}$$ 
------------------------------
## What this means for your original parameter estimation goal
If you are trying to calculate resistance and inductance from your drive data but your frame is misaligned:

   1. Apparent Resistance: The scalar $R$ term remains perfectly invariant to rotation.
   2. Inductance Distortion: You will not measure true $L_d$ or true $L_q$. Instead, you will calculate the coupled values from the $\mathbf{L}_{d'q'}$ matrix.
   3. The Back-EMF Bleed: Notice that the permanent magnet Back-EMF is no longer isolated to your observed q-axis. A component of it ($-\omega \psi_m \sin(\delta)$) has now bled directly into your $d'$-axis voltage.

Knowing that misalignment introduces these error terms, would you like to explore:

* How to use this exact matrix to calculate the unknown misalignment angle ($\delta$) directly from your measured voltage and current data?
* How this system simplifies if the motor is non-salient ($L_d = L_q$), which completely eliminates the cross-coupling inductance terms?

And in the ABC frame:

Here is the completely expanded, explicit scalar equation for Phase A. It has been arranged vertically component-by-component so you can easily trace how the phase currents, their derivatives, and the rotor position $\theta$ interact.
$$\begin{aligned} V_a = \ & R I_a \\ & + \left[ L_0 + L_g \cos(2\theta) \right] \frac{dI_a}{dt} \\ & + \left[ -\frac{1}{2}L_0 + L_g \cos\left(2\theta - \frac{2\pi}{3}\right) \right] \frac{dI_b}{dt} \\ & + \left[ -\frac{1}{2}L_0 + L_g \cos\left(2\theta + \frac{2\pi}{3}\right) \right] \frac{dI_c}{dt} \\ & - 2\omega L_g I_a \sin(2\theta) \\ & - 2\omega L_g I_b \sin\left(2\theta - \frac{2\pi}{3}\right) \\ & - 2\omega L_g I_c \sin\left(2\theta + \frac{2\pi}{3}\right) \\ & - \omega \psi_m \sin(\theta) \end{aligned}$$ 
------------------------------
## Vertical Block Guide

* Line 1: Pure copper resistive voltage drop on Phase A.
* Lines 2–4: The Transformer (Transient) Voltages. Line 2 is Phase A's self-inductance voltage drop, while Lines 3 and 4 are the mutual inductance voltage drops caused by changing currents in Phase B and Phase C.
* Lines 5–7: The Reluctance Speed Voltages. These voltages are generated purely by the physical rotation of the salient rotor iron past the three phase windings while they are carrying current.
* Line 8: The Permanent Magnet Back-EMF Voltage induced in Phase A as the rotor magnets sweep past.

Would you like to see how this long expression algebraically collapses back into the single $V_d$ or $V_q$ equation when we apply the forward Park transform to Phase A, B, and C combined?

$$\begin{aligned} \mathbf{V_a} = \ & R I_a \\ & + \left[ L_0 + L_g \cos(2\theta) \right] \frac{dI_a}{dt} \\ & + \left[ -\frac{1}{2}L_0 + L_g \cos\left(2\theta - \frac{2\pi}{3}\right) \right] \frac{dI_b}{dt} \\ & + \left[ -\frac{1}{2}L_0 + L_g \cos\left(2\theta + \frac{2\pi}{3}\right) \right] \frac{dI_c}{dt} \\ & - 2\omega L_g I_a \sin(2\theta) \\ & - 2\omega L_g I_b \sin\left(2\theta - \frac{2\pi}{3}\right) \\ & - 2\omega L_g I_c \sin\left(2\theta + \frac{2\pi}{3}\right) \\ & - \omega \psi_m \sin(\theta) \\ \\ \mathbf{V_b} = \ & R I_b \\ & + \left[ -\frac{1}{2}L_0 + L_g \cos\left(2\theta - \frac{2\pi}{3}\right) \right] \frac{dI_a}{dt} \\ & + \left[ L_0 + L_g \cos\left(2\theta + \frac{2\pi}{3}\right) \right] \frac{dI_b}{dt} \\ & + \left[ -\frac{1}{2}L_0 + L_g \cos(2\theta) \right] \frac{dI_c}{dt} \\ & - 2\omega L_g I_a \sin\left(2\theta - \frac{2\pi}{3}\right) \\ & - 2\omega L_g I_b \sin\left(2\theta + \frac{2\pi}{3}\right) \\ & - 2\omega L_g I_c \sin(2\theta) \\ & - \omega \psi_m \sin\left(\theta - \frac{2\pi}{3}\right) \\ \\ \mathbf{V_c} = \ & R I_c \\ & + \left[ -\frac{1}{2}L_0 + L_g \cos\left(2\theta + \frac{2\pi}{3}\right) \right] \frac{dI_a}{dt} \\ & + \left[ -\frac{1}{2}L_0 + L_g \cos(2\theta) \right] \frac{dI_b}{dt} \\ & + \left[ L_0 + L_g \cos\left(2\theta - \frac{2\pi}{3}\right) \right] \frac{dI_c}{dt} \\ & - 2\omega L_g I_a \sin\left(2\theta + \frac{2\pi}{3}\right) \\ & - 2\omega L_g I_b \sin(2\theta) \\ & - 2\omega L_g I_c \sin\left(2\theta - \frac{2\pi}{3}\right) \\ & - \omega \psi_m \sin\left(\theta + \frac{2\pi}{3}\right) \end{aligned}$$ 
Would you like me to write a Python function that executes these equations numerically, or should we look at how to derive the total electrical power or torque from this unified structure?

In the DQ frame is a lot saner:

$$\begin{aligned} \mathbf{V_d} = \ & R I_d \\ & + \left[ L_{avg} + L_{var}\cos(2\delta) \right] \frac{dI_d}{dt} \\ & + \left[ L_{var}\sin(2\delta) \right] \frac{dI_q}{dt} \\ & - \omega_i \left[ L_{avg} - L_{var}\cos(2\delta) \right] I_q \\ & - \omega_i \left[ L_{var}\sin(2\delta) \right] I_d \\ & - \omega_m K_e \sin(\delta) \\ \\ \mathbf{V_q} = \ & R I_q \\ & + \left[ L_{var}\sin(2\delta) \right] \frac{dI_d}{dt} \\ & + \left[ L_{avg} - L_{var}\cos(2\delta) \right] \frac{dI_q}{dt} \\ & + \omega_i \left[ L_{avg} + L_{var}\cos(2\delta) \right] I_d \\ & + \omega_i \left[ L_{var}\sin(2\delta) \right] I_q \\ & + \omega_m K_e \cos(\delta) \end{aligned}$$ 
Would you like me to translate this complete feed-forward model and its tracking gradients into a C code implementation block for your embedded microcontroller?

And the derivatives:

$$\begin{aligned} \frac{\partial \text{loss}}{\partial R} = \ & 2 \, r_d I_d \\ & + 2 \, r_q I_q \\ \\ \frac{\partial \text{loss}}{\partial L_0} = \ & 2 \, r_d \left( \frac{dI_d}{dt} - \omega_i I_q \right) \\ & + 2 \, r_q \left( \frac{dI_q}{dt} + \omega_i I_d \right) \\ \\ \frac{\partial \text{loss}}{\partial L_{bias}} = \ & 2 \, r_d \cos(2\delta)\frac{dI_d}{dt} \\ & + 2 \, r_d \sin(2\delta)\frac{dI_q}{dt} \\ & - 2 \omega_i \, r_d \sin(2\delta)I_d \\ & + 2 \omega_i \, r_d \cos(2\delta)I_q \\ & + 2 \, r_q \sin(2\delta)\frac{dI_d}{dt} \\ & - 2 \, r_q \cos(2\delta)\frac{dI_q}{dt} \\ & + 2 \omega_i \, r_q \cos(2\delta)I_d \\ & + 2 \omega_i \, r_q \sin(2\delta)I_q \\ \\ \frac{\partial \text{loss}}{\partial \delta} = \ & -4 L_{bias} \, r_d \sin(2\delta)\frac{dI_d}{dt} \\ & + 4 L_{bias} \, r_d \cos(2\delta)\frac{dI_q}{dt} \\ & - 4 \omega_i L_{bias} \, r_d \cos(2\delta)I_d \\ & - 4 \omega_i L_{bias} \, r_d \sin(2\delta)I_q \\ & - 2 \omega_m K_e \, r_d \cos(\delta) \\ & + 4 L_{bias} \, r_q \cos(2\delta)\frac{dI_d}{dt} \\ & + 4 L_{bias} \, r_q \sin(2\delta)\frac{dI_q}{dt} \\ & - 4 \omega_i L_{bias} \, r_q \sin(2\delta)I_d \\ & + 4 \omega_i L_{bias} \, r_q \cos(2\delta)I_q \\ & - 2 \omega_m K_e \, r_q \sin(\delta) \end{aligned}$$ 
Would you like me to generate a C code template or Python script to test these explicit tracking gradients in your simulator?

Last, we need to match saturation effects somehow. We're using a simplified model to just kinda match the angle of the observed residual as we probe with HFI. It seems to be fixed relative to 2 times the current angle, hence we need to depend on current x d_current_dt products to capture this behavior. The formulas I used are:

To handle $K_{sat}$ as a slow, steady motor constant and $\theta_{sat}$ as a fast, dynamic position tracking state, we must keep them as separate explicit variables.
When your arbitrary software frame is misaligned from the true physical saturation axis, the $2\times$ current vector modulation passes through a spatial phase shift of $\theta_{sat}$. By expanding the trigonometric relationships directly, your microcontroller can track the true magnetic core position online while holding the motor's saturation coefficient constant.
To keep the math tight and fast for your processor, we define your two raw current-velocity vector components as single variables:
$$A = I_d \frac{dI_d}{dt} - I_q \frac{dI_q}{dt}$$ 
$$B = I_q \frac{dI_d}{dt} + I_d \frac{dI_q}{dt}$$ 
------------------------------
## 1. Explicit Angle-Compensated Voltage Equations
Inserting $K_{sat}$ and $\theta_{sat}$ directly, the model predictions for your software frame feedforward voltages are:
$$V_{d,\text{model}} = V_{d,\text{linear}} + K_{sat} \left[ A\cos(\theta_{sat}) - B\sin(\theta_{sat}) \right]$$ 
$$V_{q,\text{model}} = V_{q,\text{linear}} + K_{sat} \left[ A\sin(\theta_{sat}) + B\cos(\theta_{sat}) \right]$$ 
------------------------------
## 2. Explicit Parameter Gradient Equations
Using your software frame voltage residuals $r_d = V_d - V_{drive,d}$ and $r_q = V_q - V_{drive,q}$, your optimizer updates the steady motor constant and the fast-moving position state using these two separate gradients:
## For the Constant Motor Saturation Magnitude ($K_{sat}$):
$$\mathbf{\frac{\partial \text{loss}}{\partial K_{sat}}} = 2 \, r_d \left[ A\cos(\theta_{sat}) - B\sin(\theta_{sat}) \right] + 2 \, r_q \left[ A\sin(\theta_{sat}) + B\cos(\theta_{sat}) \right]$$ 
## For the Dynamic Saturation Phase Angle ($\theta_{sat}$):
$$\mathbf{\frac{\partial \text{loss}}{\partial \theta_{sat}}} = 2 K_{sat} \, r_d \left[ -A\sin(\theta_{sat}) - B\cos(\theta_{sat}) \right] + 2 K_{sat} \, r_q \left[ A\cos(\theta_{sat}) - B\sin(\theta_{sat}) \right]$$ 
------------------------------

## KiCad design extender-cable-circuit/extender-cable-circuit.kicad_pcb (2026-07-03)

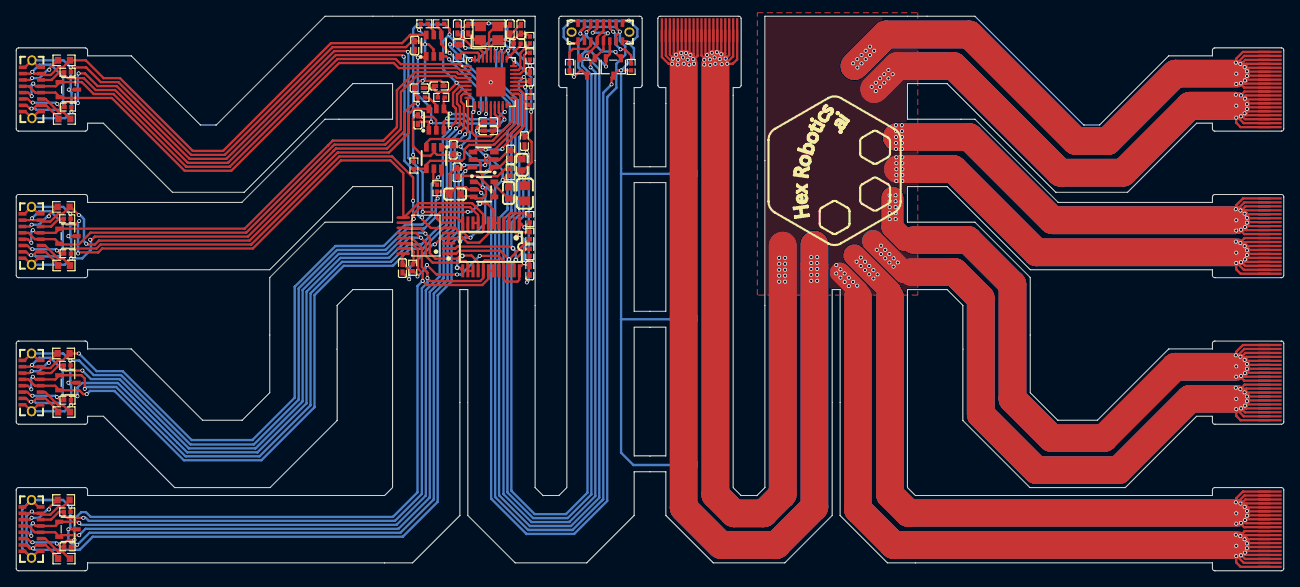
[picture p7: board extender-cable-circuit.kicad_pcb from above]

Board: 2 copper layers, 160.0 x 70.0 mm, 80 parts (0 on the bottom side), 62 nets.

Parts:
C1, C2, C4, C5, C6, C7, C10, C11, C13, C14, C15, C16, C17, C18: 100nF; C0402
C8, C12, C20: 1uF; C0603
C19: 10nF; C0402
C72, C74: 15pF; C0402
D8, D10, D12, D14, D16, D18: SOT-23-3_L3.0-W1.7-P0.95-LS2.9-BR
FPC0, FPC1, FPC2, FPC3, FPC4: FPC-20P-P0.50-Pattern
L2: 10uH; L0805
R1, R2, R3, R4, R5, R8, R9: 10kΩ; R0402
R6, R7: 5.1kΩ; R0402
R17, R18, R19, R20, R76, R77, R78, R81: 56kΩ; R0603
R35, R55, R61, R66: 20kΩ; R0402
R54: 12kΩ; R0603
R79, R80, R82, R83: 100kΩ; R0402
R96, R97, R98, R99, R103, R104, R105, R106: 1MΩ; R0402
U1: TQFN-36_L6.0-W6.0-P0.50-BL-EP3.7
U3: SOT-23-5_L3.0-W1.6-P0.95-LS2.8-BL
U7, U23, U26, U28: SOT-23-6_L2.9-W1.6-P0.95-LS2.8-BR
U9: TSSOP-24_L7.8-W4.4-P0.65-LS6.4-BL
U14: TSSOP-16_L5.0-W4.4-P0.65-LS6.4-BL
USB0, USB1, USB2, USB3, USB4: USB-C-SMD_TC-005
X3: 24MHz; CRYSTAL-SMD_4P-L3.2-W2.5-BL

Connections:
3V3: C1.2, C2.2, C5.2, C6.2, C7.2, C10.2, C12.2, C13.2, C14.2, L2.2, R1.1, R2.2, R3.2, R4.1, R5.1, R8.1, R79.1, R80.1, R82.1, R83.1, U1.5 (VDDA33), U1.10 (VDDA33), U1.15 (VDD33), U1.23 (VDD33), U1.27 (VBUS_DET), U1.29 (VDDA33), U1.36 (VDDA33), U9.2 (A1), U9.21 (A2), U9.24 (VCC), U14.16 (VDD)
/3V3-before-filter: C8.2, L2.1, U3.5 (OUT)
/CC1: R6.2, USB0.A5 (CC1)
/CC2: R7.2, USB0.B5 (CC2)
/CFG_SEL1: R9.2, U1.25 (HS_IND/CFG_SEL1)
/LDO-Bypass-Capacitor: C19.2, U3.4 (BYP)
/NRESET: R5.2, U1.26 (RESET_N)
/PLLFILT: C4.2, U1.34 (PLLFILT)
/RBIAS: R54.1, U1.35 (RBIAS)
/XTAL1: C72.1, U1.33 (XTALIN/CLKIN), X3.1 (OSC1)
/XTAL2: C74.2, U1.32 (XTALOUT), X3.3 (OSC2)
/servo-usb-connector1/CC1x: R77.1, USB2.A5 (CC1)
/servo-usb-connector1/CC2x: R18.1, USB2.B5 (CC2)
/servo-usb-connector1/ILIMx: R55.2, U23.5 (ILIM)
/servo-usb-connector1/VBUSx: R18.2, R77.2, U23.6 (OUT), USB2.A4 (VBUS), USB2.A9 (VBUS), USB2.B4 (VBUS), USB2.B9 (VBUS)
/servo-usb-connector2/CC1x: R78.1, USB3.A5 (CC1)
/servo-usb-connector2/CC2x: R19.1, USB3.B5 (CC2)
/servo-usb-connector2/ILIMx: R61.2, U26.5 (ILIM)
/servo-usb-connector2/VBUSx: R19.2, R78.2, U26.6 (OUT), USB3.A4 (VBUS), USB3.A9 (VBUS), USB3.B4 (VBUS), USB3.B9 (VBUS)
/servo-usb-connector3/CC1x: R81.1, USB4.A5 (CC1)
/servo-usb-connector3/CC2x: R20.1, USB4.B5 (CC2)
/servo-usb-connector3/ILIMx: R66.2, U28.5 (ILIM)
/servo-usb-connector3/VBUSx: R20.2, R81.2, U28.6 (OUT), USB4.A4 (VBUS), USB4.A9 (VBUS), USB4.B4 (VBUS), USB4.B9 (VBUS)
/servo-usb-connector/CC1x: R76.1, USB1.A5 (CC1)
/servo-usb-connector/CC2x: R17.1, USB1.B5 (CC2)
/servo-usb-connector/ILIMx: R35.2, U7.5 (ILIM)
/servo-usb-connector/VBUSx: R17.2, R76.2, U7.6 (OUT), USB1.A4 (VBUS), USB1.A9 (VBUS), USB1.B4 (VBUS), USB1.B9 (VBUS)
GND: C1.1, C2.1, C4.1, C5.1, C6.1, C7.1, C8.1, C10.1, C11.1, C12.1, C13.1, C14.1, C15.1, C16.1, C17.1, C18.1, C19.1, C20.1, C72.2, C74.1, D8.3 (K), D10.3 (K), D12.3 (K), D14.3 (K), D16.3 (K), D18.3 (K), FPC0.1, FPC0.2, FPC0.3, FPC0.4, FPC0.5, FPC0.6, FPC0.7, FPC0.8, FPC0.9, FPC0.10, FPC1.1, FPC1.2, FPC1.3, FPC1.4, FPC1.5, FPC1.6, FPC1.7, FPC1.8, FPC1.9, FPC1.10, FPC2.1, FPC2.2, FPC2.3, FPC2.4, FPC2.5, FPC2.6, FPC2.7, FPC2.8, FPC2.9, FPC2.10, FPC3.1, FPC3.2, FPC3.3, FPC3.4, FPC3.5, FPC3.6, FPC3.7, FPC3.8, FPC3.9, FPC3.10, FPC4.1, FPC4.2, FPC4.3, FPC4.4, FPC4.5, FPC4.6, FPC4.7, FPC4.8, FPC4.9, FPC4.10, R6.1, R7.1, R9.1, R35.1, R54.2, R55.1, R61.1, R66.1, R96.1, R97.1, R98.1, R99.1, R103.1, R104.1, R105.1, R106.1, U1.37 (EP), U3.2 (GND), U7.2 (GND), U9.1 (A0), U9.12 (GND), U14.3 (A0), U14.4 (A1), U14.5 (A2), U14.8 (VSS), U23.2 (GND), U26.2 (GND), U28.2 (GND), USB0.A1 (GND), USB0.A12 (GND), USB0.B1 (GND), USB0.B12 (GND), USB1.1 (EH), USB1.2 (EH), USB1.A1 (GND), USB1.A12 (GND), USB1.B1 (GND), USB1.B12 (GND), USB2.1 (EH), USB2.2 (EH), USB2.A1 (GND), USB2.A12 (GND), USB2.B1 (GND), USB2.B12 (GND), USB3.1 (EH), USB3.2 (EH), USB3.A1 (GND), USB3.A12 (GND), USB3.B1 (GND), USB3.B12 (GND), USB4.1 (EH), USB4.2 (EH), USB4.A1 (GND), USB4.A12 (GND), USB4.B1 (GND), USB4.B12 (GND), X3.2 (GND), X3.4 (GND)
I2C_SCL: D10.2 (A1), R2.1, U1.24 (SCL/SMBCLK/CFG_SEL0), U9.22 (SCL), U14.1 (SCL), USB0.A8 (SUB1)
I2C_SDA: D10.1 (A1), R3.1, U1.22 (SDA/SMBBATA/NON_REM1), U9.23 (SDA), U14.2 (SDA), USB0.B8 (SUB2)
IN_USB_D+: D8.2 (A1), U1.31 (USBDP_UP), USB0.A6 (DP1), USB0.B6 (DP2)
IN_USB_D-: D8.1 (A1), U1.30 (USBDM_UP), USB0.A7 (DN1), USB0.B7 (DN2)
unnamed: C11.2, U1.14 (CRFILT)
unnamed: R8.2, U1.28 (SUSP_IND/LOCAL_PWR/NON_REM0)
unnamed: R1.2, U9.3 (RESET#)
unnamed: R4.2, U14.15 (RESET#)
PRTPWR1: U1.12 (PRTPWR1/BC_EN1), U7.3 (EN)
PRTPWR2: U1.16 (PRTPWR2/BC_EN2), U23.3 (EN)
PRTPWR3: U1.18 (PRTPWR3/BC_EN3), U26.3 (EN)
PRTPWR4: U1.20 (PRTPWR4/BC_EN4), U28.3 (EN)
SERVO1_BOOT0: R96.2, U9.4 (SD0), U9.7 (SC1), U14.6 (IO0), USB1.A8 (SUB1)
SERVO1_NRST: R103.2, U9.5 (SC0), U9.6 (SD1), U14.7 (IO1), USB1.B8 (SUB2)
SERVO2_BOOT0: R97.2, U9.8 (SD2), U9.11 (SC3), U14.9 (IO2), USB2.A8 (SUB1)
SERVO2_NRST: R104.2, U9.9 (SC2), U9.10 (SD3), U14.10 (IO3), USB2.B8 (SUB2)
SERVO3_BOOT0: R98.2, U9.13 (SD4), U9.16 (SC5), U14.11 (IO4), USB3.A8 (SUB1)
SERVO3_NRST: R105.2, U9.14 (SC4), U9.15 (SD5), U14.12 (IO5), USB3.B8 (SUB2)
SERVO4_BOOT0: R99.2, U9.17 (SD6), U9.20 (SC7), U14.13 (IO6), USB4.A8 (SUB1)
SERVO4_NRST: R106.2, U9.18 (SC6), U9.19 (SD7), U14.14 (IO7), USB4.B8 (SUB2)
USBDN1_D+: D12.2 (A1), U1.2 (USBDP_DN1/PRT_DIS_P1), USB1.A6 (DP1), USB1.B6 (DP2)
USBDN1_D-: D12.1 (A1), U1.1 (USBDM_DN1/PRT_DIS_M1), USB1.A7 (DN1), USB1.B7 (DN2)
USBDN2_D+: D14.2 (A1), U1.4 (USBDP_DN2/PRT_DIS_P2), USB2.A6 (DP1), USB2.B6 (DP2)
USBDN2_D-: D14.1 (A1), U1.3 (USBDM_DN2/PRT_DIS_M2), USB2.A7 (DN1), USB2.B7 (DN2)
USBDN3_D+: D16.2 (A1), U1.7 (USBDP_DN3/PRT_DIS_P3), USB3.A6 (DP1), USB3.B6 (DP2)
USBDN3_D-: D16.1 (A1), U1.6 (USBDM_DN3/PRT_DIS_M3), USB3.A7 (DN1), USB3.B7 (DN2)
USBDN4_D+: D18.2 (A1), U1.9 (USBDP_DN4/PRT_DIS_P4), USB4.A6 (DP1), USB4.B6 (DP2)
USBDN4_D-: D18.1 (A1), U1.8 (USBDM_DN4/PRT_DIS_M4), USB4.A7 (DN1), USB4.B7 (DN2)
VBUS: C15.2, C16.2, C17.2, C18.2, C20.2, U3.1 (IN), U3.3 (EN), U7.1 (IN), U23.1 (IN), U26.1 (IN), U28.1 (IN), USB0.A4 (VBUS), USB0.A9 (VBUS), USB0.B4 (VBUS), USB0.B9 (VBUS)
VCC: FPC0.11, FPC0.12, FPC0.13, FPC0.14, FPC0.15, FPC0.16, FPC0.17, FPC0.18, FPC0.19, FPC0.20, FPC1.11, FPC1.12, FPC1.13, FPC1.14, FPC1.15, FPC1.16, FPC1.17, FPC1.18, FPC1.19, FPC1.20, FPC2.11, FPC2.12, FPC2.13, FPC2.14, FPC2.15, FPC2.16, FPC2.17, FPC2.18, FPC2.19, FPC2.20, FPC3.11, FPC3.12, FPC3.13, FPC3.14, FPC3.15, FPC3.16, FPC3.17, FPC3.18, FPC3.19, FPC3.20, FPC4.11, FPC4.12, FPC4.13, FPC4.14, FPC4.15, FPC4.16, FPC4.17, FPC4.18, FPC4.19, FPC4.20
nOCS1: R79.2, U1.13 (OCS_N1), U7.4 (/FAULT)
nOCS2: R80.2, U1.17 (OCS_N2), U23.4 (/FAULT)
nOCS3: R82.2, U1.19 (OCS_N3), U26.4 (/FAULT)
nOCS4: R83.2, U1.21 (OCS_N4), U28.4 (/FAULT)

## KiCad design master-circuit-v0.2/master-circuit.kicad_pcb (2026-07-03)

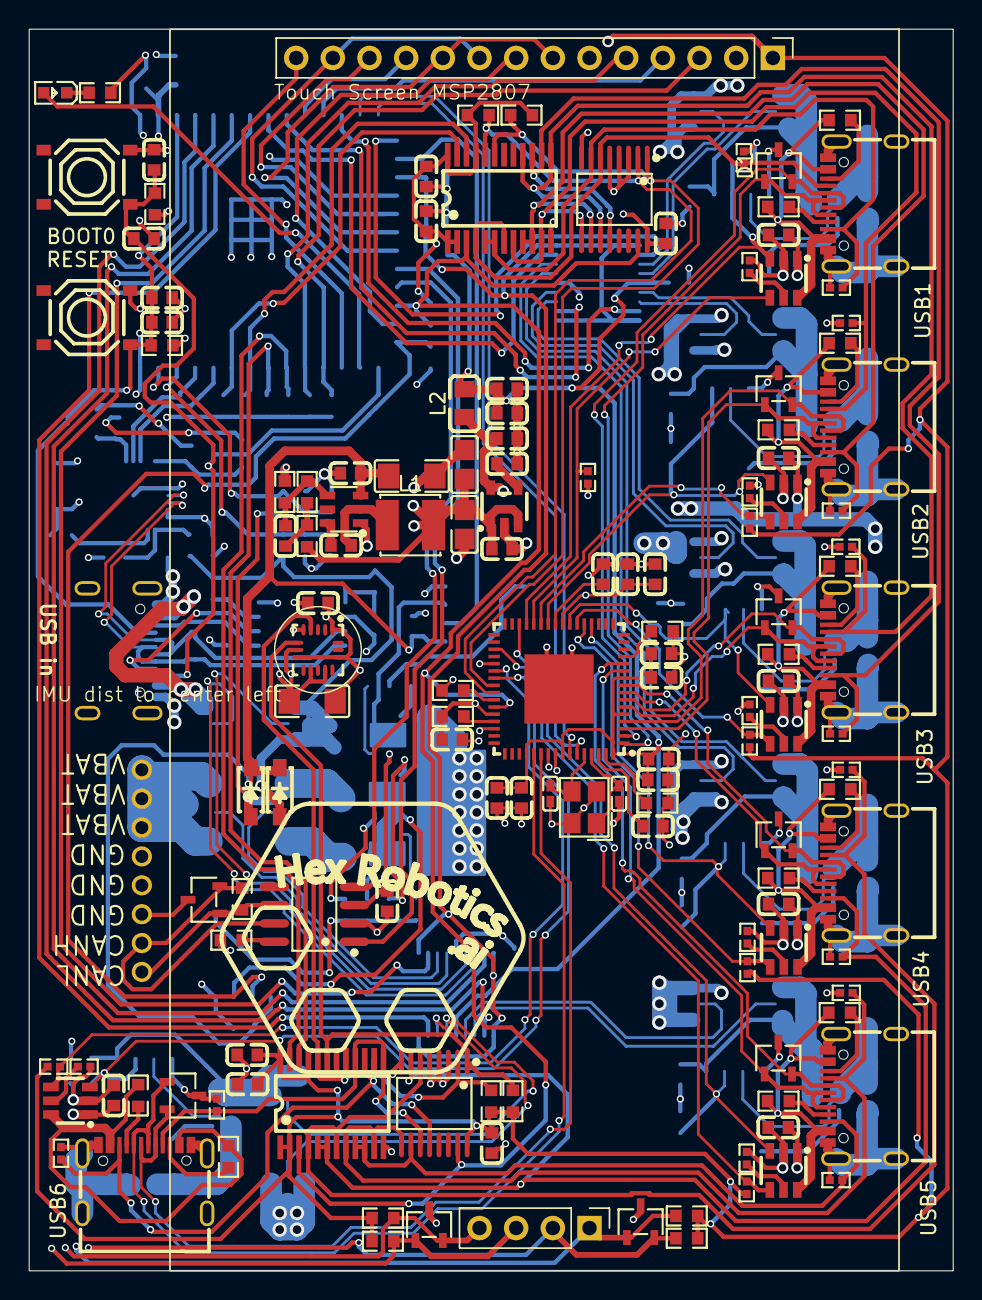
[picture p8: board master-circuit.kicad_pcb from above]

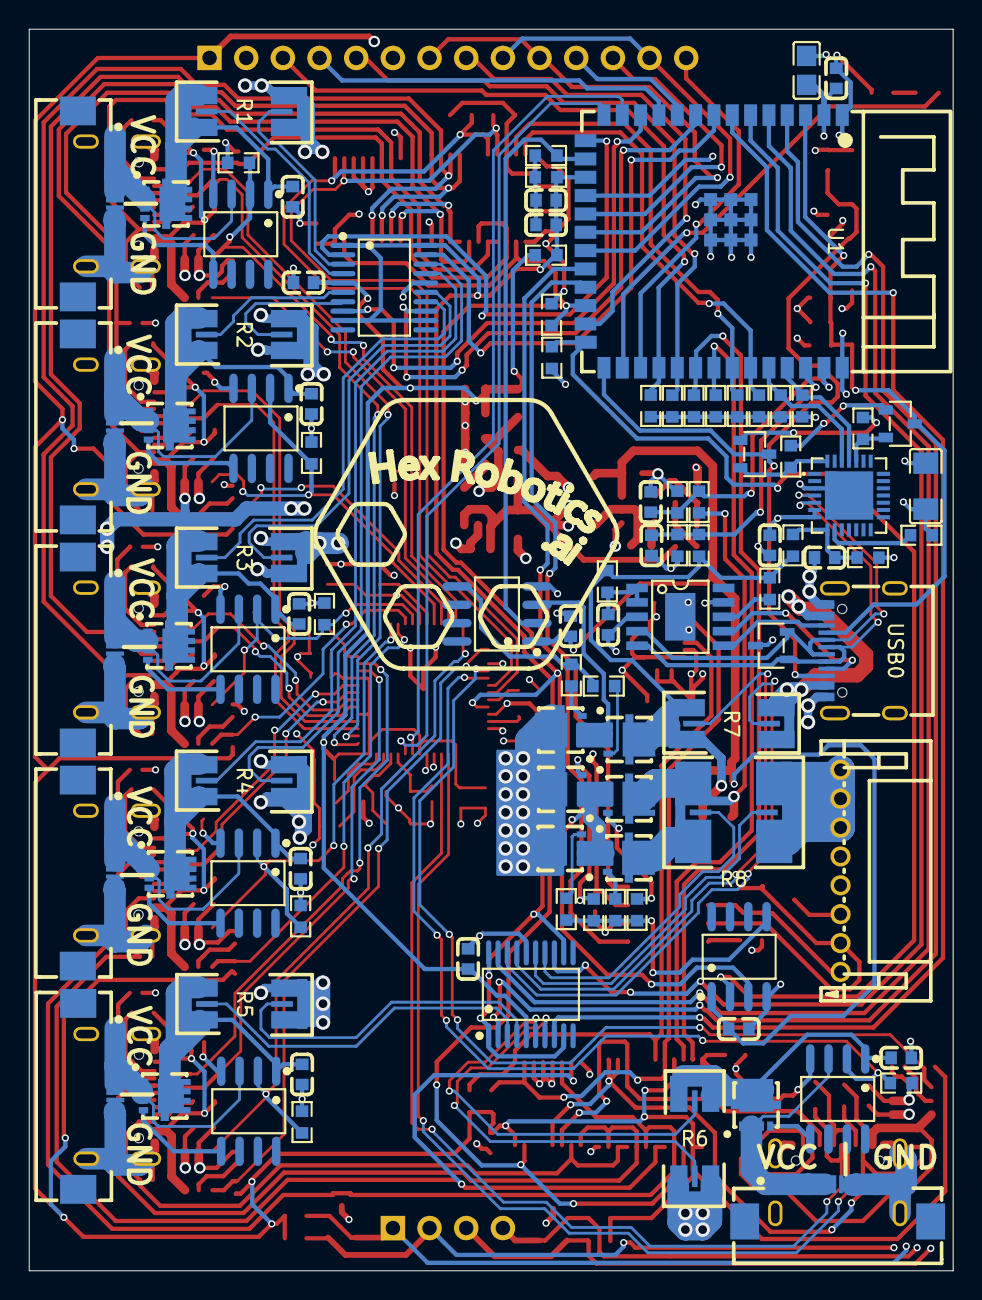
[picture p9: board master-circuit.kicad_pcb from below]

Board: 4 copper layers, 64.0 x 86.0 mm, 238 parts (100 on the bottom side), 184 nets.

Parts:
C1, C8, C12, C15, C18, C20, C25, C26, C27, C28, C29, C33, C35, C40, C51, C52, C53, C54, C55, C56, C57, C58, C59, C63, C65, C71, C84, C85: 1uF; C0603
C2, C4, C5, C7, C13, C16, C22, C30, C31, C34, C38, C39, C42, C43, C44, C45, C60, C61, C62, C66, C67, C68, C70: 100nF; C0603
C3, C23, C24: 22uF; C0805
C6: 100pF; C0603
C9: 10nF; C0603
C10, C11: 1nF; C0603
C17, C21, C32: 10uF; C1206
C64, C69: 15pF; C0402
D1, D2, D4, D5, D6, D7, D8, D9, D10, D11: SOT-23-3_L3.0-W1.7-P0.95-LS2.9-BR
D12, D14: SOD-123_L2.7-W1.6-LS3.7-RD-1
FPC1, FPC2, FPC3, FPC4, FPC5, FPC6: FPC-SMD_20P-P0.50_XUNPU_FPC-05F-20PH20
L1: 15uH; IND-SMD_L4.0-W4.0
L2: 10uH; L0805
LED1: LED0603-RD
Q8, Q12, Q14, Q16, Q18, Q20, Q21, Q22, Q23, Q24, Q25, Q26: WDFN-5_L3.1-W3.1-P0.65-BL_1
Q9, Q10: SOT-23-3_L2.9-W1.3-P1.90-LS2.4-BR
R1, R2, R3, R4, R5, R6, R7: 5mΩ; R2512 Shunt with Kelvin connections
R8: 1mΩ; R2725 Shunt with Kelvin connections
R9, R11, R12, R14, R15, R17, R18, R21, R22, R24, R25, R26, R27, R29, R30, R31, R32, R33, R34, R37, R38, R42, R43, R44, R47, R51, R52, R53, R58, R60, R64, R72, R73, R74, R78, R95, R102, R109: 10kΩ; R0603
R10: 49.9Ω; R0603
R13, R28, R46, R59, R65, R71, R76, R85, R86, R87, R88, R89: 56kΩ; R0603
R16: 120Ω; R0603
R23, R39: 1.5kΩ; R0603
R35, R55, R61, R66, R67, R70: 20kΩ; R0402
R40: 20kΩ; R0603
R41: 47kΩ; R0603
R45, R48, R56: 100kΩ; R0603
R50: 12kΩ; R0603
R62: 13kΩ; R0603
R68: 1kΩ; R0603
R77, R81, R90, R92, R93, R94: 4.7Ω; R0603
R79, R80, R82, R83, R84, R91: 100kΩ; R0402
R96, R97, R98, R99, R100, R101, R103, R104, R105, R106, R107, R108: 1MΩ; R0402
SW1, SW2: SW-SMD_4P-L5.1-W5.1-P3.70-LS6.5-TL_H1.5
U1: WIRELM-SMD_ESP32-S3-WROOM-1
U3: SOT-23-5_L3.0-W1.6-P0.95-LS2.8-BL
U4: SOT-23-6_L2.9-W1.6-P0.95-LS2.8-BL
U7, U23, U26, U28, U30, U32: SOT-23-6_L2.9-W1.6-P0.95-LS2.8-BR
U9, U13: TSSOP-24_L7.8-W4.4-P0.65-LS6.4-BL
U10: QFN-28_L5.0-W5.0-P0.50-TL-EP3.3
U11, U16: TSSOP-20_L6.5-W4.4-P0.65-LS6.4-BL
U14, U15: TSSOP-16_L5.0-W4.4-P0.65-LS6.4-BL
U17, U41, U43, U44, U45, U46, U47, U48, U49: SOIC-8_L4.9-W3.9-P1.27-LS6.0-BL
U18: LGA-16_L3.0-W3.0-P0.50-TL
U19: CONN-TH_S8B-PH-K-S-LF-SN
U24: QFN-64_L9.0-W9.0-P0.50-BL-EP4.8
U35: MSP2807 OLED with touchescreen and SD card
U42: ESSOP-10_L4.9-W3.9-P1.0-LS6.0-TL-EP
USB0, USB1, USB2, USB3, USB4, USB5, USB6: USB-C-SMD_TYPE-C16PIN
X2: 24MHz; CRYSTAL-SMD_4P-L3.2-W2.5-BL

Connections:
3V3: C2.2, C3.2, C8.2, C16.2, C17.2, C30.2, C31.2, C32.2, C42.2, C43.2, C44.2, C45.2, C59.2, C60.2, C68.2, C84.2, C85.2, L2.1, R9.2, R14.2, R15.2, R17.2, R18.2, R24.2, R25.2, R26.2, R27.2, R29.2, R32.2, R33.2, R34.2, R37.2, R39.1, R42.1, R51.2, R53.2, R58.2, R60.2, R64.2, R79.1, R80.1, R82.1, R83.1, R84.1, R91.1, U1.2 (3V3), U3.5 (OUT), U9.1 (A0), U9.2 (A1), U9.21 (A2), U9.24 (VCC), U10.6 (VDD), U10.7 (VREGIN), U13.1 (A0), U13.2 (A1), U13.21 (A2), U13.24 (VCC), U14.16 (VDD), U15.16 (VDD), U17.3 (VCC), U18.1 (VDD_IO), U18.8 (CS), U18.14 (VDD), U24.24 (VDD33CR), U24.37 (OCS7_N), U24.44 (VBUS_DET), U24.46 (VDD33), U35.1 (VCC)
3V3A: C12.2, C13.2, C38.2, C39.2, C61.2, C62.2, C66.2, C67.2, C70.2, C71.2, L2.2, R21.2, U11.5 (VS), U16.5 (VS), U24.5 (VDDA33), U24.10 (VDDA33), U24.52 (VDDA33), U24.57 (VDDA33), U24.64 (VDD33PLL)
5V: C15.2, C20.2, C23.2, C24.2, C26.2, C27.2, C28.2, C33.2, C40.2, L1.2, R10.2, U3.1 (IN), U3.3 (EN), U7.1 (IN), U23.1 (IN), U26.1 (IN), U28.1 (IN), U30.1 (IN), U32.1 (IN)
+Probe-1: R1.4 (Probe-2), U11.3 (IN±1)
+Probe-2: R2.4 (Probe-2), U11.7 (IN±2)
+Probe-3: R3.4 (Probe-2), U11.15 (IN+3)
+Probe-4: R4.4 (Probe-2), U11.18 (IN±4)
+Probe-5: R5.4 (Probe-2), U16.4 (IN+1)
+Probe-6: R6.4 (Probe-2), U16.7 (IN±2)
+Probe-7: R7.4 (Probe-2), U16.17 (IN+4)
+Probe-8: R8.4 (Probe-2), U16.14 (IN±3)
-Probe-1: R1.3 (Probe-1), U11.4 (IN+1)
-Probe-2: R2.3 (Probe-1), U11.6 (IN+2)
-Probe-3: R3.3 (Probe-1), U11.14 (IN±3)
-Probe-4: R4.3 (Probe-1), U11.17 (IN+4)
-Probe-5: R5.3 (Probe-1), U16.3 (IN±1)
-Probe-6: R6.3 (Probe-1), U16.6 (IN+2)
-Probe-7: R7.3 (Probe-1), U16.18 (IN±4)
-Probe-8: R8.3 (Probe-1), U16.15 (IN+3)
/Buck-Bootstrap-Capacitor: C7.1, U4.6 (BOOT)
/Buck-Output-SW: C7.2, L1.1, U4.2 (SW)
/Buck-Probe-Point: C6.2, R10.1, R56.2
/CAN-RS-SLOPE_CONTROL: R31.2, U17.8 (RS)
/CFG_SEL1: R52.2, U24.42 (HS_IND/CFG_SEL1)
/CFG_SEL2: R30.2, U24.13 (CFG_SEL2)
/DTR-GATE: Q9.1 (B), R43.1
/Gate1-vbattery: Q18.4 (G), R90.2
/Gate1-vbus: Q14.4 (G), R81.2
/Gate2-vbattery: Q20.4 (G), R92.2
/Gate2-vbus: Q16.4 (G), R77.2
/Gate3-vbattery: Q21.4 (G), R93.2
/Gate4-vbattery: Q22.4 (G), R94.2
/LDO-Bypass-Capacitor: C9.2, U3.4 (BYP)
/PD-VBUS-DETECT: R72.2, U42.8 (VBUS)
/PD-VDD: C29.2, R68.2, U42.1 (VDD), U42.2 (CFG2)
/RBIAS: R50.1, U24.63 (RBIAS)
/RTS-GATE: Q10.1 (B), R44.1
/Source-vbattery: Q18.1 (S), Q18.2 (S), Q18.3 (S), Q20.1 (S), Q20.2 (S), Q20.3 (S), Q21.1 (S), Q21.2 (S), Q21.3 (S), Q22.1 (S), Q22.2 (S), Q22.3 (S), U47.3 (Source)
/Source-vbus: Q14.1 (S), Q14.2 (S), Q14.3 (S), Q16.1 (S), Q16.2 (S), Q16.3 (S), U46.3 (Source)
/VBATTERY_PINS: R8.1 (Shunt-1), U19.6, U19.7, U19.8
/VDD18PLL: C65.2, U24.62 (VDD18PLL)
/XTAL1: C64.1, U24.61 (XTAL1/CLKIN), X2.1 (OSC1)
/XTAL2: C69.2, U24.60 (XTAL2), X2.3 (OSC2)
/servo-usb-connector1/CC1x: R28.2, USB2.A5 (CC1)
/servo-usb-connector1/CC2x: R85.1, USB2.B5 (CC2)
/servo-usb-connector1/ILIMx: R55.2, U23.5 (ILIM)
/servo-usb-connector1/VBUSx: R28.1, R85.2, U23.6 (OUT), USB2.A4B9 (VBUS), USB2.B4A9 (VBUS)
/servo-usb-connector1/VCCx: FPC2.1, FPC2.2, FPC2.3, FPC2.4, FPC2.5, FPC2.6, FPC2.7, FPC2.8, FPC2.9, FPC2.10, Q12.1 (S), Q12.2 (S), Q12.3 (S), U43.3 (Source)
/servo-usb-connector1/VCCx-probe: C52.2, Q12.5 (D), R2.1 (Shunt-1), U43.1 (V+)
/servo-usb-connector2/CC1x: R46.2, USB3.A5 (CC1)
/servo-usb-connector2/CC2x: R86.1, USB3.B5 (CC2)
/servo-usb-connector2/ILIMx: R61.2, U26.5 (ILIM)
/servo-usb-connector2/VBUSx: R46.1, R86.2, U26.6 (OUT), USB3.A4B9 (VBUS), USB3.B4A9 (VBUS)
/servo-usb-connector2/VCCx: FPC3.1, FPC3.2, FPC3.3, FPC3.4, FPC3.5, FPC3.6, FPC3.7, FPC3.8, FPC3.9, FPC3.10, Q23.1 (S), Q23.2 (S), Q23.3 (S), U44.3 (Source)
/servo-usb-connector2/VCCx-probe: C53.2, Q23.5 (D), R3.1 (Shunt-1), U44.1 (V+)
/servo-usb-connector3/CC1x: R59.2, USB4.A5 (CC1)
/servo-usb-connector3/CC2x: R87.1, USB4.B5 (CC2)
/servo-usb-connector3/ILIMx: R66.2, U28.5 (ILIM)
/servo-usb-connector3/VBUSx: R59.1, R87.2, U28.6 (OUT), USB4.A4B9 (VBUS), USB4.B4A9 (VBUS)
/servo-usb-connector3/VCCx: FPC4.1, FPC4.2, FPC4.3, FPC4.4, FPC4.5, FPC4.6, FPC4.7, FPC4.8, FPC4.9, FPC4.10, Q24.1 (S), Q24.2 (S), Q24.3 (S), U45.3 (Source)
/servo-usb-connector3/VCCx-probe: C54.2, Q24.5 (D), R4.1 (Shunt-1), U45.1 (V+)
/servo-usb-connector4/CC1x: R65.2, USB5.A5 (CC1)
/servo-usb-connector4/CC2x: R88.1, USB5.B5 (CC2)
/servo-usb-connector4/ILIMx: R67.2, U30.5 (ILIM)
/servo-usb-connector4/VBUSx: R65.1, R88.2, U30.6 (OUT), USB5.A4B9 (VBUS), USB5.B4A9 (VBUS)
/servo-usb-connector4/VCCx: FPC5.1, FPC5.2, FPC5.3, FPC5.4, FPC5.5, FPC5.6, FPC5.7, FPC5.8, FPC5.9, FPC5.10, Q25.1 (S), Q25.2 (S), Q25.3 (S), U48.3 (Source)
/servo-usb-connector4/VCCx-probe: C57.2, Q25.5 (D), R5.1 (Shunt-1), U48.1 (V+)
/servo-usb-connector5/CC1x: R71.2, USB6.A5 (CC1)
/servo-usb-connector5/CC2x: R89.1, USB6.B5 (CC2)
/servo-usb-connector5/ILIMx: R70.2, U32.5 (ILIM)
/servo-usb-connector5/VBUSx: R71.1, R89.2, U32.6 (OUT), USB6.A4B9 (VBUS), USB6.B4A9 (VBUS)
/servo-usb-connector5/VCCx: FPC6.1, FPC6.2, FPC6.3, FPC6.4, FPC6.5, FPC6.6, FPC6.7, FPC6.8, FPC6.9, FPC6.10, Q26.1 (S), Q26.2 (S), Q26.3 (S), U49.3 (Source)
/servo-usb-connector5/VCCx-probe: C58.2, Q26.5 (D), R6.1 (Shunt-1), U49.1 (V+)
/servo-usb-connector/CC1x: R13.2, USB1.A5 (CC1)
/servo-usb-connector/CC2x: R76.1, USB1.B5 (CC2)
/servo-usb-connector/ILIMx: R35.2, U7.5 (ILIM)
/servo-usb-connector/VBUSx: R13.1, R76.2, U7.6 (OUT), USB1.A4B9 (VBUS), USB1.B4A9 (VBUS)
/servo-usb-connector/VCCx: FPC1.1, FPC1.2, FPC1.3, FPC1.4, FPC1.5, FPC1.6, FPC1.7, FPC1.8, FPC1.9, FPC1.10, Q8.1 (S), Q8.2 (S), Q8.3 (S), U41.3 (Source)
/servo-usb-connector/VCCx-probe: C51.2, Q8.5 (D), R1.1 (Shunt-1), U41.1 (V+)
BATTERY_CURRENT: U1.6 (IO6), U16.13 (OUT3)
BATTERY_VOLTAGE: C11.2, R38.2, R48.1, U1.39 (IO1)
BOOT0: C4.2, C25.2, Q10.3 (C), R42.2, SW1.1 (A), U1.27 (IO0), USB0.B8 (SBU2)
Buck-FB: C6.1, R56.1, R62.2, U4.4 (FB)
CANH: D7.2 (A1), R16.2, U17.7 (CANH), U19.2
CANL: D7.1 (A1), R16.1, U17.6 (CANL), U19.1
CAN_RX: U1.23 (IO21), U17.4 (R)
CAN_TX: U1.22 (IO14), U17.1 (D)
CC1: U42.7 (CC1), USB0.A5 (CC1)
CC2: U42.6 (CC2), USB0.B5 (CC2)
CONNECT_BATTERY: R11.2, U1.26 (IO45), U47.2 (Input)
CONNECT_VBUS: R12.2, U1.16 (IO46), U46.2 (Input)
DTR: Q10.2 (E), R43.2, U10.28 (DTR)
ENABLE-ESP32: C1.2, C5.2, Q9.3 (C), R37.1, SW2.1 (A), U1.3 (EN), USB0.A8 (SBU1)
FSPICLK/SPI2_CLK: D4.2 (A1), R14.1, U1.20 (IO12), U35.7 (SCK), U35.10 (T_CLK), U35.18 (SD_SCK)
FSPICS0/MEMORY_CS: D6.1 (A1), R9.1, U1.18 (IO10), U35.15 (SD_CS)
FSPID/SPI2_MOSI: D6.2 (A1), R34.1, U1.19 (IO11), U35.6 (SDI/MOSI), U35.12 (T_DIN), U35.16 (SD_MOSI)
FSPIQ/SPI2_MISO: D4.1 (A1), R15.1, U1.21 (IO13), U35.9 (SD0/MISO), U35.13 (T_DO), U35.17 (SD_MISO)
GND: C1.1, C2.1, C3.1, C4.1, C5.1, C8.1, C9.1, C10.1, C11.1, C12.1, C13.1, C15.1, C16.1, C17.1, C18.2, C20.1, C21.1, C22.1, C23.1, C24.1, C25.1, C26.1, C27.1, C28.1, C29.1, C30.1, C31.1, C32.1, C33.1, C34.1, C35.1, C38.1, C39.1, C40.1, C42.1, C43.1, C44.1, C45.1, C51.1, C52.1, C53.1, C54.1, C55.1, C56.1, C57.1, C58.1, C59.1, C60.1, C61.1, C62.1, C63.1, C64.2, C65.1, C66.1, C67.1, C68.1, C69.1, C70.1, C71.1, C84.1, C85.1, D1.3 (K), D2.3 (K), D4.3 (K), D5.3 (K), D6.3 (K), D7.3 (K), D8.3 (K), D9.3 (K), D10.3 (K), D11.3 (K), FPC1.11, FPC1.12, FPC1.13, FPC1.14, FPC1.15, FPC1.16, FPC1.17, FPC1.18, FPC1.19, FPC1.20, FPC2.11, FPC2.12, FPC2.13, FPC2.14, FPC2.15, FPC2.16, FPC2.17, FPC2.18, FPC2.19, FPC2.20, FPC3.11, FPC3.12, FPC3.13, FPC3.14, FPC3.15, FPC3.16, FPC3.17, FPC3.18, FPC3.19, FPC3.20, FPC4.11, FPC4.12, FPC4.13, FPC4.14, FPC4.15, FPC4.16, FPC4.17, FPC4.18, FPC4.19, FPC4.20, FPC5.11, FPC5.12, FPC5.13, FPC5.14, FPC5.15, FPC5.16, FPC5.17, FPC5.18, FPC5.19, FPC5.20, FPC6.11, FPC6.12, FPC6.13, FPC6.14, FPC6.15, FPC6.16, FPC6.17, FPC6.18, FPC6.19, FPC6.20, R11.1, R12.1, R22.1, R23.2, R30.1, R31.1, R35.1, R38.1, R41.2, R47.1, R50.2, R52.1, R55.1, R61.1, R62.1, R66.1, R67.1, R70.1, R73.1, R74.1, R78.1, R95.1, R96.1, R97.1, R98.1, R99.1, R100.1, R101.1, R102.1, R103.1, R104.1, R105.1, R106.1, R107.1, R108.1, R109.1, SW1.3 (C), SW2.3 (C), U1.1 (GND), U1.40 (GND), U1.41 (GND), U3.2 (GND), U4.1 (GND), U7.2 (GND), U9.12 (GND), U10.3 (GND), U10.29 (EP), U11.16 (GND), U13.12 (GND), U14.3 (A0), U14.4 (A1), U14.5 (A2), U14.8 (VSS), U15.3 (A0), U15.4 (A1), U15.5 (A2), U15.8 (VSS), U16.16 (GND), U17.2 (GND), U18.5 (GND), U18.7 (SDO/SA0), U18.10 (RES), U18.12 (GND), U19.3, U19.4, U19.5, U23.2 (GND), U24.55 (USBDN7_DM/PRT_DIS_M7), U24.56 (USBDN7_DP/PRT_DIS_P7), U24.65 (EP), U26.2 (GND), U28.2 (GND), U30.2 (GND), U32.2 (GND), U35.2 (GND), U41.4 (GND), U42.3 (CFG3), U42.9 (CFG1), U42.11 (GND), U43.4 (GND), U44.4 (GND), U45.4 (GND), U46.4 (GND), U47.4 (GND), U48.4 (GND), U49.4 (GND), USB0.A1B12 (GND), USB0.B1A12 (GND), USB1.1 (SHELL), USB1.2 (SHELL), USB1.3 (SHELL), USB1.4 (SHELL), USB1.A1B12 (GND), USB1.B1A12 (GND), USB2.1 (SHELL), USB2.2 (SHELL), USB2.3 (SHELL), USB2.4 (SHELL), USB2.A1B12 (GND), USB2.B1A12 (GND), USB3.1 (SHELL), USB3.2 (SHELL), USB3.3 (SHELL), USB3.4 (SHELL), USB3.A1B12 (GND), USB3.B1A12 (GND), USB4.1 (SHELL), USB4.2 (SHELL), USB4.3 (SHELL), USB4.4 (SHELL), USB4.A1B12 (GND), USB4.B1A12 (GND), USB5.1 (SHELL), USB5.2 (SHELL), USB5.3 (SHELL), USB5.4 (SHELL), USB5.A1B12 (GND), USB5.B1A12 (GND), USB6.1 (SHELL), USB6.2 (SHELL), USB6.3 (SHELL), USB6.4 (SHELL), USB6.A1B12 (GND), USB6.B1A12 (GND), X2.2 (GND), X2.4 (GND)
GUEST_USB_D+: D8.2 (A1), U10.4 (D+), U42.4 (DP), USB0.A6 (DP1), USB0.B6 (DP2)
GUEST_USB_D-: D8.1 (A1), U10.5 (D-), U42.5 (DM), USB0.A7 (DN1), USB0.B7 (DN2)
I2C1_INTERNAL_SCL: R53.1, U9.19 (SD7), U14.1 (SCL), U24.40 (SDA/SMBDATA/NON_REM1)
I2C1_INTERNAL_SDA: R58.1, U9.20 (SC7), U14.2 (SDA), U24.41 (SCL/SMBCLK/CFG_SEL0)
I2C1_SCL: R24.1, U1.34 (IO41), U9.22 (SCL)
I2C1_SDA: R25.1, U1.35 (IO42), U9.23 (SDA)
I2C2_INTERNAL_SCL: R60.1, U13.19 (SD7), U15.1 (SCL), U18.6 (SDA/SDI/SDO)
I2C2_INTERNAL_SDA: R64.1, U13.20 (SC7), U15.2 (SDA), U18.4 (SCL/SPC)
I2C2_SCL: R18.1, U1.33 (IO40), U13.22 (SCL)
I2C2_SDA: R17.1, U1.32 (IO39), U13.23 (SDA)
INTERNAL_GUEST_USB_D+: U1.14 (IO20), U24.59 (USBUP_DP)
INTERNAL_GUEST_USB_D-: U1.13 (IO19), U24.58 (USBUP_DM)
NRESET_ALL_MULTIPLEXERS: R29.1, U1.24 (IO47), U9.3 (RESET#), U13.3 (RESET#), U14.15 (RESET#), U15.15 (RESET#), U24.43 (RESET_N)
unnamed: LED1.1 (K), R23.1
unnamed: Q8.4 (G), U41.5 (Gate)
unnamed: Q12.4 (G), U43.5 (Gate)
unnamed: Q23.4 (G), U44.5 (Gate)
unnamed: Q24.4 (G), U45.5 (Gate)
unnamed: Q25.4 (G), U48.5 (Gate)
unnamed: Q26.4 (G), U49.5 (Gate)
unnamed: R39.2, U10.9 (RSTb)
unnamed: C18.1, R40.2, R41.1, U10.8 (VBUS)
unnamed: R51.1, U24.45 (SUSP_IND/LOCAL_PWR/NON_REM0)
unnamed: C63.2, U24.25 (VDD18)
unnamed: R77.1, R81.1, U46.5 (Gate)
unnamed: R90.1, R92.1, R93.1, R94.1, U47.5 (Gate)
PRTPWR1: R73.2, U7.3 (EN), U24.29 (PRTPWR1), U41.2 (Input)
PRTPWR2: R74.2, U23.3 (EN), U24.26 (PRTPWR2), U43.2 (Input)
PRTPWR3: R78.2, U24.23 (PRTPWR3), U26.3 (EN), U44.2 (Input)
PRTPWR4: R95.2, U24.20 (PRTPWR4), U28.3 (EN), U45.2 (Input)
PRTPWR5: R102.2, U24.30 (PRTPWR5), U30.3 (EN), U48.2 (Input)
PRTPWR6: R109.2, U24.39 (PRTPWR6), U32.3 (EN), U49.2 (Input)
REFERENCE: C34.2, C35.2, R21.1, R22.2, U1.17 (IO9), U11.1 (REF1), U11.9 (REF2), U11.12 (REF3), U11.20 (REF4), U16.1 (REF1), U16.9 (REF2), U16.12 (REF3), U16.20 (REF4)
RTS: Q9.2 (E), R44.2, U10.24 (RTS)
RX: R32.1, U1.36 (RXD0), U10.26 (TXD)
SCREEN_CS: R27.1, U1.30 (IO37), U35.3 (CS)
SCREEN_DC: R26.1, U1.31 (IO38), U35.5 (DC)
SCREEN_LED: U1.25 (IO48), U35.8 (LED)
SCREEN_RESET: U1.11 (IO18), U35.4 (RESET)
SERVO1_BOOT0: R103.2, U9.4 (SD0), U9.7 (SC1), U14.6 (IO0), USB1.A8 (SBU1)
SERVO1_CURRENT: U1.15 (IO3), U11.2 (OUT1)
SERVO1_NRST: R96.2, U9.5 (SC0), U9.6 (SD1), U14.7 (IO1), USB1.B8 (SBU2)
SERVO2_BOOT0: R104.2, U9.8 (SD2), U9.11 (SC3), U14.9 (IO2), USB2.A8 (SBU1)
SERVO2_CURRENT: U1.12 (IO8), U11.8 (OUT2)
SERVO2_NRST: R97.2, U9.9 (SC2), U9.10 (SD3), U14.10 (IO3), USB2.B8 (SBU2)
SERVO3_BOOT0: R105.2, U9.13 (SD4), U9.16 (SC5), U14.11 (IO4), USB3.A8 (SBU1)
SERVO3_CURRENT: U1.9 (IO16), U11.13 (OUT3)
SERVO3_NRST: R98.2, U9.14 (SC4), U9.15 (SD5), U14.12 (IO5), USB3.B8 (SBU2)
SERVO4_BOOT0: R106.2, U13.4 (SD0), U13.7 (SC1), U15.6 (IO0), USB4.A8 (SBU1)
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

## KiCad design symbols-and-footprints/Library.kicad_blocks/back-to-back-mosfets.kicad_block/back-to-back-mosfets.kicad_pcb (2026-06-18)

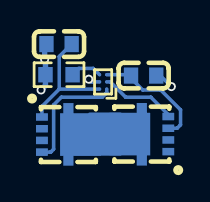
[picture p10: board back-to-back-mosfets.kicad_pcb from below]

Board: 4 copper layers, 6 parts (6 on the bottom side), 7 nets.

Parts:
C29, C49: 1uF; C0603
Q5, Q6: WDFN-5_L3.1-W3.1-P0.65-BL_1
R36: 10kΩ; R0603
U12: WLCSP-6_L1.2-W0.8-P0.40-TL

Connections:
/VBUS_PROBE: C29.2, Q5.1 (S), Q5.2 (S), Q5.3 (S), U12.C1 (VOUT)
/back-to-back-mosfets/GATE1x: Q6.4 (G), U12.A1 (VGATE1)
/back-to-back-mosfets/GATE2x: Q5.4 (G), U12.B1 (VGATE2)
/back-to-back-mosfets/Mid-MOSFETSx: Q5.5 (D), Q6.5 (D)
CONNECT_VBUS: R36.2, U12.C2 (VCT)
GND: C29.1, C49.1, R36.1, U12.B2 (GND)
VBUS: C49.2, Q6.1 (S), Q6.2 (S), Q6.3 (S), U12.A2 (VIN)

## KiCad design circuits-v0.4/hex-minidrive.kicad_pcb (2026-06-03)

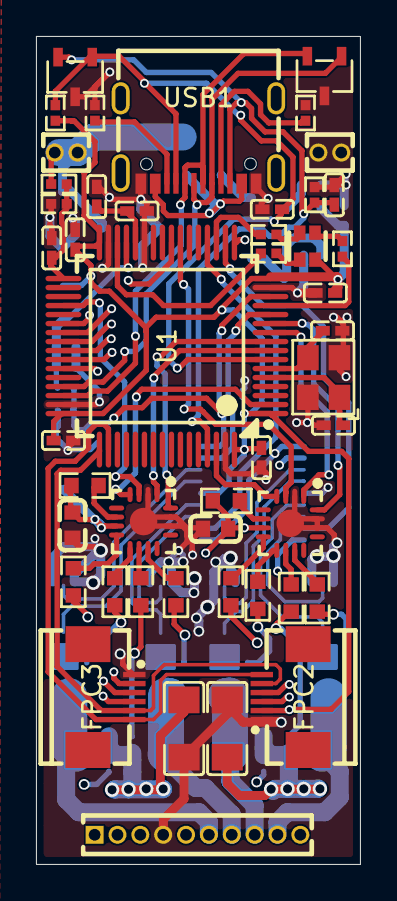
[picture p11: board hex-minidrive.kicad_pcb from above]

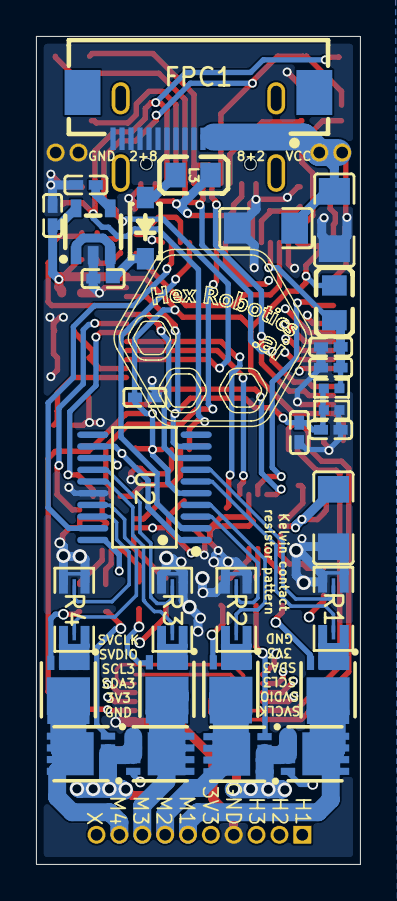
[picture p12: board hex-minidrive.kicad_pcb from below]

Board: 4 copper layers, 18.0 x 46.0 mm, 78 parts (31 on the bottom side), 80 nets.

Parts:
C0, C1, C2, C3, C4: 10uF; C1206
C21, C101, C106, C108, C109, C110, C111, C112, C113, C114: 100nF; C0402
C31, C32, C102, C105, C107: 1uF; C0402
C33: 10nF; C0402
C103, C104: 15pF; C0402
C115: 1nF; C0402
C501, C601: 100nF; C0603
D1: SOD-123_L2.7-W1.6-LS3.7-RD-1
D2, D3: SOT-23-3_L3.0-W1.7-P0.95-LS2.9-BR
FPC1: FPC-SMD_20P-P0.50_XUNPU_FPC-05F-20PH20
FPC2, FPC3: FPC-SMD_6P-P0.50_XUNPU_FPC-05F-6PH20
H1: 10P 1.27mm header; HDR-TH_HX-PZ1.27-1X10P-ZZ
H2, H3: 2P-1.27mm-header; HDR-TH_2P-P1.27-V-M-2
L2: 10uH; L0805
L3: 300mΩ; L0805
LED1: LED-ARRAY-SMD_4P-L1.6-W1.5-BR_XL-1615RGBC-RF
Q1, Q3, Q5, Q7: DFN-8_L3.0-W3.0-P0.65-BL-MOSFET_shifted
Q2, Q4, Q6, Q8: DFN-8_L3.0-W3.0-P0.65-BL-MOSFET
R1, R2, R3, R4: 10mΩ; R1206 Shunt with Kelvin connections
R5, R6: 5.1kΩ; R0402
R11, R12, R13, R14, R19: 10kΩ; R0402
R15, R16, R17: 1.5kΩ; R0402
R18: 100kΩ; R0402
R101, R102, R201, R202, R301, R302, R401, R402: 4.7Ω; R0603
R501, R601: 10Ω; R0603
U1: LQFP-64_L10.0-W10.0-P0.50-LS12.0-BL
U2: TSSOP-20_L6.5-W4.4-P0.65-LS6.4-BL
U3: SOT-23-5_L3.0-W1.6-P0.95-LS2.8-BL
U5, U6: QFN-16_L3.0-W3.0-P0.50-TL-EP1.7
USB1: USB-C-SMD_TYPE-C16PIN
X1: 16MHz; OSC-SMD_4P-L3.2-W2.5-BL

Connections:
3V3: C21.2, C32.2, C109.2, C111.2, C112.2, C113.2, FPC2.2, FPC3.2, H1.5, L2.1, LED1.2 (COM+), R14.1, U1.1 (VBAT), U1.16 (VDD), U1.32 (VDD), U1.48 (VDD), U1.64 (VDD), U2.5 (VS), U3.5 (OUT)
3V3A: C101.2, C102.2, L2.2, R13.2, U1.29 (VDDA)
5V: C31.2, D1.1 (-), U3.1 (IN), U3.3 (EN)
+Probe-1: R1.3 (Probe-1), U2.6 (IN+2)
+Probe-2: R2.3 (Probe-1), U2.4 (IN+1)
+Probe-3: R3.3 (Probe-1), U2.15 (IN+3)
+Probe-4: R4.3 (Probe-1), U2.17 (IN+4)
-Probe-1: R1.4 (Probe-2), U2.7 (IN±2)
-Probe-2: R2.4 (Probe-2), U2.3 (IN±1)
-Probe-3: R3.4 (Probe-2), U2.14 (IN±3)
-Probe-4: R4.4 (Probe-2), U2.18 (IN±4)
/Blue-LED: LED1.3 (B-), R16.1
/Driver1-internal-LDO: R501.2, U5.6 (VCC1)
/Driver2-internal-LDO: R601.2, U6.6 (VCC1)
/Gate-1-Negative: Q1.2 (G), R101.2
/Gate-1-Positive: Q2.2 (G), R102.1
/Gate-2-Negative: Q3.2 (G), R201.2
/Gate-2-Positive: Q4.2 (G), R202.1
/Gate-3-Negative: Q5.2 (G), R301.2
/Gate-3-Positive: Q6.2 (G), R302.1
/Gate-4-Negative: Q7.2 (G), R401.2
/Gate-4-Positive: Q8.2 (G), R402.1
/Green-LED: LED1.4 (G-), R15.1
/LDO-Bypass-Capacitor: C33.2, U3.4 (BYP)
/OSC1: C103.2, U1.5 (PF0-OSC_IN), X1.1 (OSC1)
/OSC2: C104.2, U1.6 (PF1-OSC_OUT), X1.3 (OSC2)
/Red-LED: LED1.1 (R-), R17.2
/Shunt-1: Q1.1 (S), R1.1 (Shunt-1)
/Shunt-2: Q3.1 (S), R2.1 (Shunt-1)
/Shunt-3: Q5.1 (S), R3.1 (Shunt-1)
/Shunt-4: Q7.1 (S), R4.1 (Shunt-1)
/USB:5V: L3.1, USB1.A4B9 (VBUS), USB1.B4A9 (VBUS)
/USB:5V-filtered: D1.2 (+), L3.2
/USB:CC1: R6.2, USB1.A5 (CC1)
/USB:CC2: R5.2, USB1.B5 (CC2)
ADC1_IN1/M1_CURRENT: U1.12 (PA0), U2.8 (OUT2)
ADC1_IN3/HALF_VREF: C107.2, C108.2, R12.2, R13.1, U1.14 (PA2), U2.1 (REF1), U2.9 (REF2), U2.12 (REF3), U2.20 (REF4)
ADC1_IN4/M3_CURRENT: U1.17 (PA3), U2.13 (OUT3)
ADC2_IN3/M2_CURRENT: U1.20 (PA6), U2.2 (OUT1)
ADC2_IN14/VOLTAGE: C115.2, R18.1, R19.2, U1.33 (PB11)
ADC2_IN17/M4_CURRENT: U1.18 (PA4), U2.19 (OUT4)
BOOT0/STOP: C114.2, D3.2 (A1), R11.2, U1.61 (PB8-BOOT0), USB1.B8 (SBU2)
GND: C0.1, C1.1, C2.1, C3.1, C4.1, C21.1, C31.1, C32.1, C33.1, C101.1, C102.1, C103.1, C104.1, C105.1, C106.1, C107.1, C108.1, C109.1, C110.1, C111.1, C112.1, C113.1, C114.1, C115.1, C501.1, C601.1, D2.3 (K), D3.3 (K), FPC1.11, FPC1.12, FPC1.13, FPC1.14, FPC1.15, FPC1.16, FPC1.17, FPC1.18, FPC1.19, FPC1.20, FPC2.1, FPC3.1, H1.4, H2.1, H2.2, R1.2 (Shunt-2), R2.2 (Shunt-2), R3.2 (Shunt-2), R4.2 (Shunt-2), R5.1, R6.1, R11.1, R12.1, R19.1, U1.15 (VSS), U1.27 (VSSA), U1.31 (VSS), U1.47 (VSS), U1.63 (VSS), U2.16 (GND), U3.2 (GND), U5.2 (LIN3), U5.14 (GND), U5.15 (HIN3), U5.17 (EP), U6.2 (LIN3), U6.14 (GND), U6.15 (HIN3), U6.17 (EP), USB1.A1B12 (GND), USB1.B1A12 (GND), X1.2 (GND), X1.4 (GND)
I2C2_SCL: FPC2.4, U1.43 (PA9)
I2C2_SDA: FPC2.3, U1.42 (PA8)
I2C3_SCL: FPC3.4, U1.40 (PC8)
I2C3_SDA: FPC3.3, U1.41 (PC9)
M1: H1.6, Q1.3 (D), Q2.3 (D)
M2: H1.7, Q3.3 (D), Q4.3 (D)
M3: H1.8, Q5.3 (D), Q6.3 (D)
M4: H1.9, Q7.3 (D), Q8.3 (D)
N-Gate-1: R101.1, U5.9 (LO1)
N-Gate-2: R201.1, U5.11 (LO2)
N-Gate-3: R301.1, U6.9 (LO1)
N-Gate-4: R401.1, U6.11 (LO2)
NRST: C110.2, D3.1 (A1), R14.2, U1.7 (PG10-NRST), USB1.A8 (SBU1)
P-Gate-1: R102.2, U5.8 (HO1)
P-Gate-2: R202.2, U5.10 (HO2)
P-Gate-3: R302.2, U6.8 (HO1)
P-Gate-4: R402.2, U6.10 (HO2)
SYS_JTCK-SWCLK: FPC2.6, FPC3.6, U1.50 (PA14)
SYS_JTMS-SVDIO: FPC2.5, FPC3.5, U1.49 (PA13)
TIM1_CH1: U1.8 (PC0), U5.1 (HIN1)
TIM1_CH1N: U1.2 (PC13), U5.4 (LIN1)
TIM1_CH2: U1.9 (PC1), U5.16 (HIN2)
TIM1_CH2N: U1.36 (PB14), U5.3 (LIN2)
TIM1_CH3: U1.10 (PC2), U6.1 (HIN1)
TIM1_CH3N: U1.62 (PB9), U6.4 (LIN1)
TIM1_CH4: U1.11 (PC3), U6.16 (HIN2)
TIM1_CH4N: U1.23 (PC5), U6.3 (LIN2)
TIM2_CH1/GREEN_LED: R15.2, U1.19 (PA5)
TIM2_CH2/BLUE_LED: R16.2, U1.13 (PA1)
TIM2_CH3/RED_LED: R17.1, U1.30 (PB10)
TIM3_CH1/ENCODER_1: H1.1, U1.38 (PC6)
TIM3_CH2/ENCODER_2: H1.2, U1.39 (PC7)
TIM3_CH3/ENCODER_3: H1.3, U1.24 (PB0)
USB_D_N: D2.1 (A1), U1.45 (PA11), USB1.A7 (DN1), USB1.B7 (DN2)
USB_D_P: D2.2 (A1), U1.46 (PA12), USB1.A6 (DP1), USB1.B6 (DP2)
VCC: C0.2, C1.2, C2.2, C3.2, C4.2, C501.2, C601.2, FPC1.1, FPC1.2, FPC1.3, FPC1.4, FPC1.5, FPC1.6, FPC1.7, FPC1.8, FPC1.9, FPC1.10, H3.1, H3.2, Q2.1 (S), Q4.1 (S), Q6.1 (S), Q8.1 (S), R18.2, R501.1, R601.1, U5.7 (VCC2), U6.7 (VCC2)
VREF: C105.2, C106.2, U1.28 (VREF+)

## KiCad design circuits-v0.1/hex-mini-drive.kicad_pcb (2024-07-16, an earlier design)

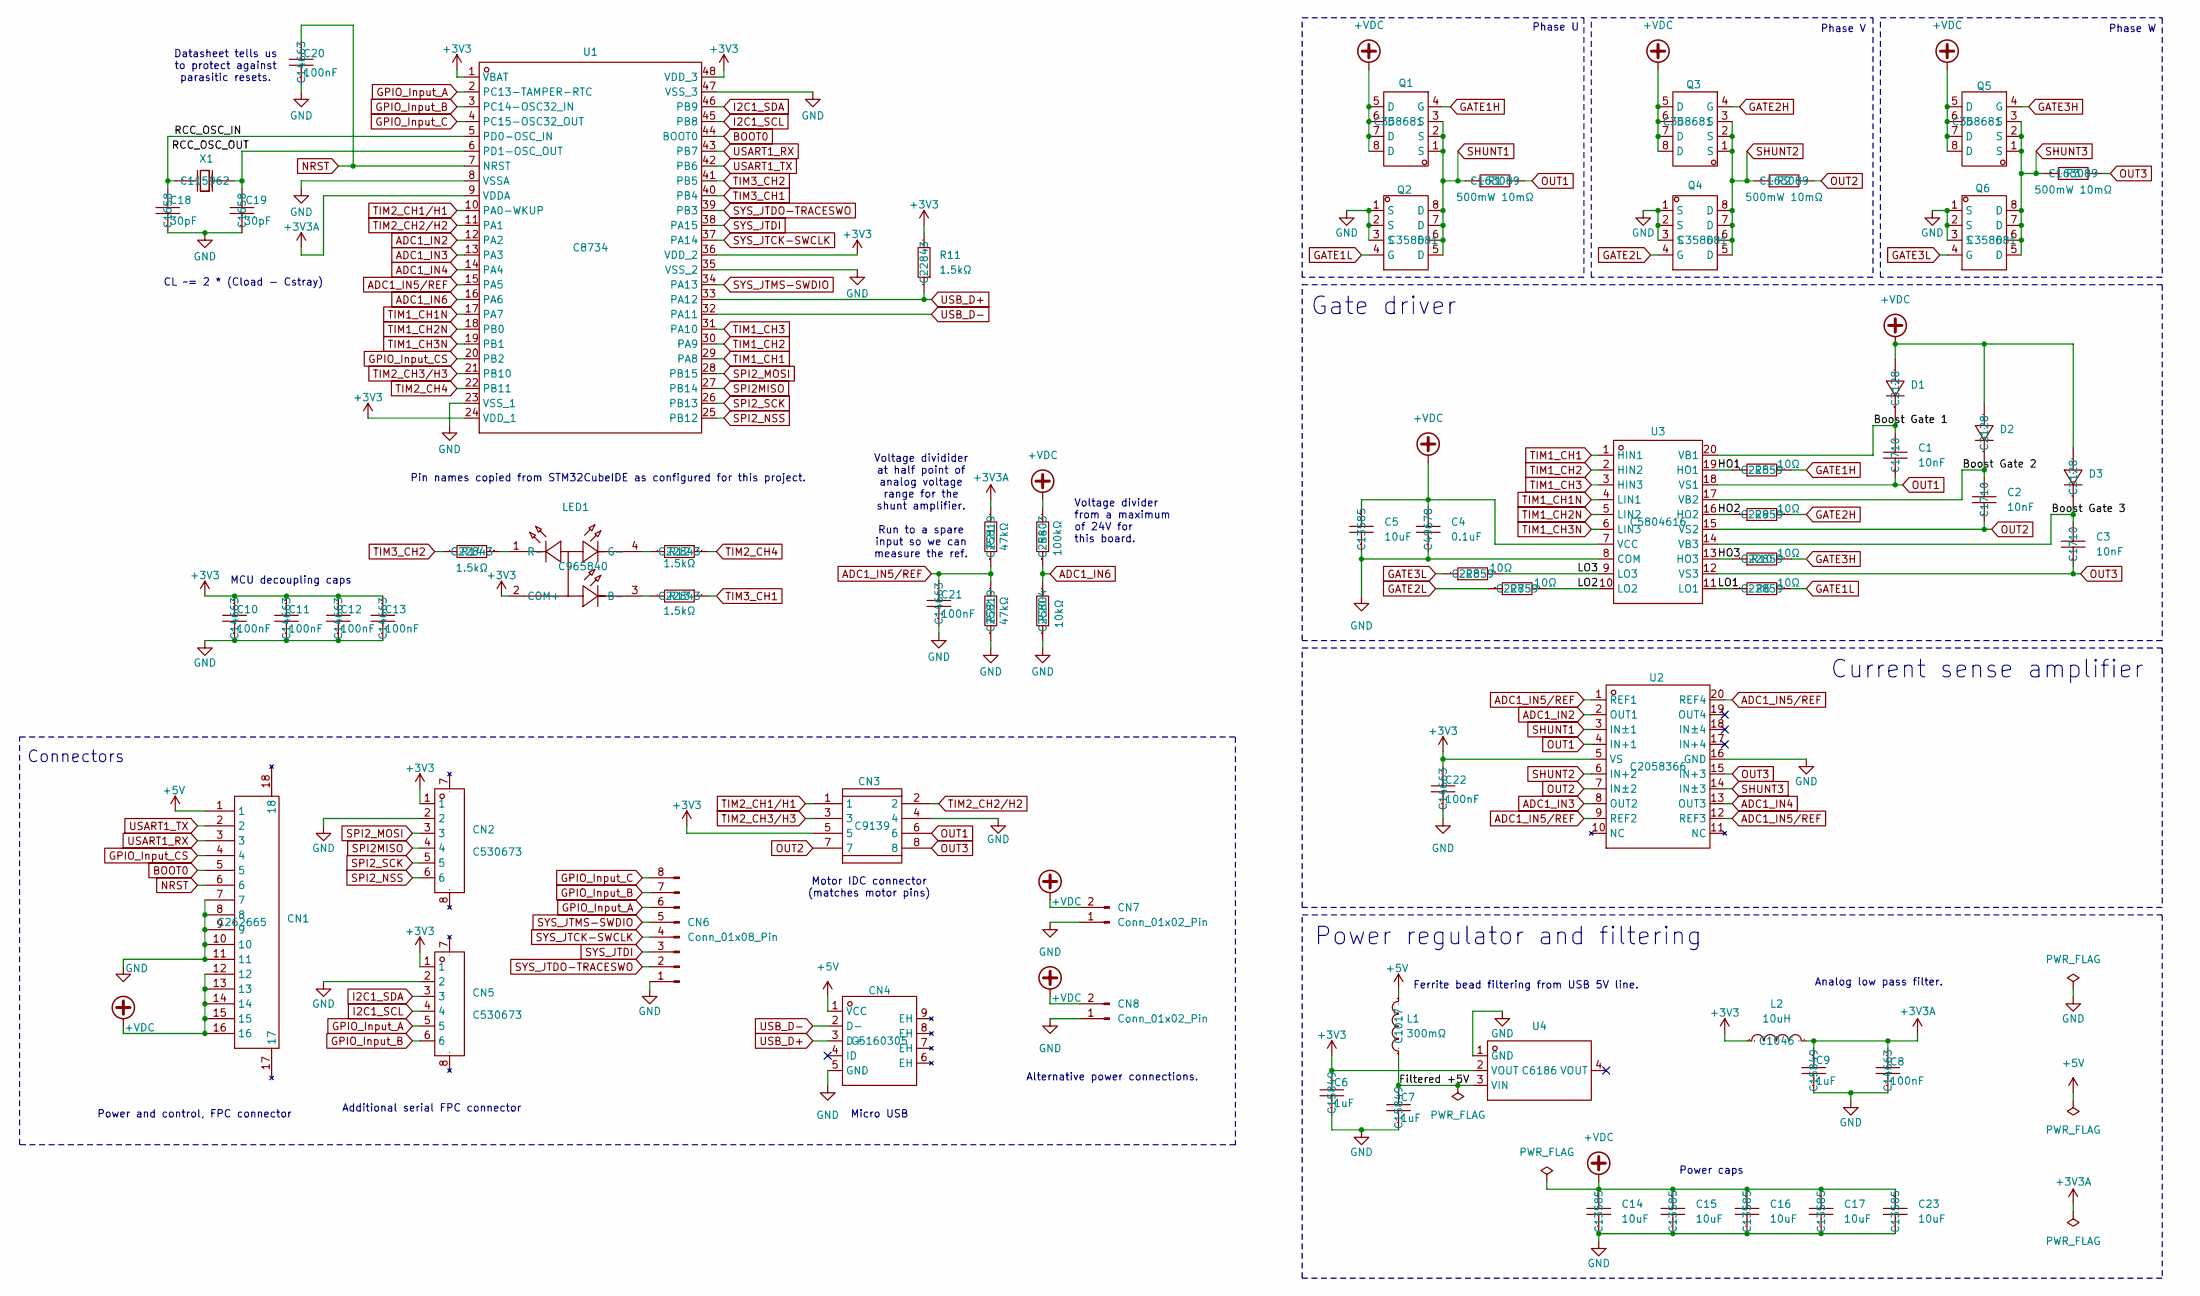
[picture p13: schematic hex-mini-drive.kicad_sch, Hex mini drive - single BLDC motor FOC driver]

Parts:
C1, C2, C3: 10nF; C0805; LCSC Part # C1710
C4: 0.1uF; C0805; LCSC Part # C49678
C5, C14, C15, C16, C17, C23: 10uF; C1206; LCSC Part # C13585
C6, C7, C9: 1uF; C0603; Manufacturer Part CL10A105KB8NNNC; LCSC Part Name 1uF ±10% 50V
C8, C10, C11, C12, C13, C20, C21, C22: 100nF; C0603; Manufacturer Part CC0603KRX7R9BB104; LCSC Part Name 100nF ±10% 50V
C18, C19: 30pF; C0603; Manufacturer Part 0603CG300J500NT; LCSC Part Name 30pF ±5% 50V
CN1: FPC-SMD_P0.50-16P_FGS-XJ-H2.0; Manufacturer Part AFC01-S16FCA-00; LCSC Part Name 间距:0.5mm P数:16P 翻盖式 下接
CN2, CN5: FPC-SMD_6P-P0.50_L3.8-W5.0; Manufacturer Part KH-0.5-H3.25-6PIN; LCSC Part Name 间距:0.5mm P数:6P 翻盖式 下接
CN3: IDC-TH_8P-P2.54-H-R2-C4-S2.54; LCSC Part # C9139
CN4: MICRO-USB-SMD_MICRONJ5P-1.0-1.25; LCSC Part # C5160305
CN6: Conn_01x08_Pin; PinHeader_1x08_P1.00mm_Vertical
CN7, CN8: Conn_01x02_Pin; PinHeader_1x02_P2.00mm_Vertical
D1, D2, D3: IN4148WS T4 SOD-323_L1.8-W1.3-LS2.5-RD; LCSC Part # C2128
L1: 300mΩ; L0805; Manufacturer Part GZ2012D601TF; LCSC Part Name 单路 0805磁珠 阻抗600Ω@100MHz
L2: 10uH; L0805; Manufacturer Part SDFL2012S100KTF; LCSC Part Name 10uH ±10%
LED1: LED-ARRAY-SMD_4P-L1.6-W1.5-BR_XL-1615RGBC-RF; Manufacturer Part XL-1615RGBC-RF; LCSC Part Name XL-1615RGBC-RF
Q1, Q2, Q3, Q4, Q5, Q6: AO4266E SOIC-8_L4.9-W3.9-P1.27-LS6.0-BL; LCSC Part # C358681
R1, R2, R3: 500mW 10mΩ; R0805; Manufacturer Part RLM10FTSMR010; LCSC Part Name 10mΩ ±1% 500mW
R4: 100kΩ; R0603; LCSC Part # C25803
R5, R6, R7, R8, R9, R10: 10Ω; R0603; Manufacturer Part 0603WAF100JT5E; LCSC Part Name 10Ω ±1% 100mW 厚膜电阻
R11, R12, R13, R14: 1.5kΩ; R0603; Manufacturer Part 0603WAF1501T5E; LCSC Part Name 1.5kΩ ±1% 100mW 厚膜电阻
R20: 10kΩ; R0603; LCSC Part # C25804
R21, R22: 47kΩ; R0603; LCSC Part # C25819
U1: STM32F103C8T6 LQFP-48_L7.0-W7.0-P0.50-LS9.0-BL; LCSC Part # C8734
U2: INA4181A1 TSSOP-20_L6.5-W4.4-P0.65-LS6.4-BL; LCSC Part # C2058366
U3: FD6288T TSSOP-20_L6.5-W4.4-P0.65-LS6.4-BL; LCSC Part # C5804616
U4: AMS1117-3.3 SOT-223-3_L6.5-W3.4-P2.30-LS7.0-BR; Manufacturer Part AMS1117-3.3; LCSC Part Name 输出3.3V 1A
X1: CRYSTAL-SMD_L5.0-W3.2; LCSC Part # C115962

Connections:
+3V3: C6.2, C10.2, C11.2, C12.2, C13.2, C22.2, CN2.1, CN3.5, CN5.1, L2.1, LED1.2 (COM+), R11.2, U1.1 (VBAT), U1.24 (VDD_1), U1.36 (VDD_2), U1.48 (VDD_3), U2.5 (VS), U4.2 (VOUT)
+3V3A: C8.2, C9.2, L2.2, R21.2, U1.9 (VDDA)
+5V: CN1.1, CN4.1 (VCC), L1.2
+VDC: C4.2, C5.2, C14.1, C15.1, C16.1, C17.1, C23.1, CN1.12, CN1.13, CN1.14, CN1.15, CN1.16, CN7.2, CN8.2, D1.2 (A), D2.2 (A), D3.2 (A), Q1.5 (D), Q1.6 (D), Q1.7 (D), Q1.8 (D), Q3.5 (D), Q3.6 (D), Q3.7 (D), Q3.8 (D), Q5.5 (D), Q5.6 (D), Q5.7 (D), Q5.8 (D), R4.2, U3.7 (VCC)
/Boost Gate 1: C1.2, D1.1 (K), U3.20 (VB1)
/Boost Gate 2: C2.2, D2.1 (K), U3.17 (VB2)
/Boost Gate 3: C3.2, D3.1 (K), U3.14 (VB3)
/Filtered +5V: C7.2, L1.1, U4.3 (VIN)
/HO1: R5.1, U3.19 (HO1)
/HO2: R9.1, U3.16 (HO2)
/HO3: R10.1, U3.13 (HO3)
/LO1: R6.1, U3.11 (LO1)
/LO2: R7.2, U3.10 (LO2)
/LO3: R8.2, U3.9 (LO3)
/RCC_OSC_IN: C18.2, U1.5 (PD0-OSC_IN), X1.1 (OSC1)
/RCC_OSC_OUT: C19.2, U1.6 (PD1-OSC_OUT), X1.2 (OSC2)
ADC1_IN2: U1.12 (PA2), U2.2 (OUT1)
ADC1_IN3: U1.13 (PA3), U2.8 (OUT2)
ADC1_IN4: U1.14 (PA4), U2.13 (OUT3)
ADC1_IN5/REF: C21.2, R21.1, R22.2, U1.15 (PA5), U2.1 (REF1), U2.9 (REF2), U2.12 (REF3), U2.20 (REF4)
ADC1_IN6: R4.1, R20.2, U1.16 (PA6)
BOOT0: CN1.5, U1.44 (BOOT0)
GATE1H: Q1.4 (G), R5.2
GATE1L: Q2.4 (G), R6.2
GATE2H: Q3.4 (G), R9.2
GATE2L: Q4.4 (G), R7.1
GATE3H: Q5.4 (G), R10.2
GATE3L: Q6.4 (G), R8.1
GND: C4.1, C5.1, C6.1, C7.1, C8.1, C9.1, C10.1, C11.1, C12.1, C13.1, C14.2, C15.2, C16.2, C17.2, C18.1, C19.1, C20.1, C21.1, C22.1, C23.2, CN1.7, CN1.8, CN1.9, CN1.10, CN1.11, CN2.2, CN3.4, CN4.5 (GND), CN5.2, CN6.1, CN7.1, CN8.1, Q2.1 (S), Q2.2 (S), Q2.3 (S), Q4.1 (S), Q4.2 (S), Q4.3 (S), Q6.1 (S), Q6.2 (S), Q6.3 (S), R20.1, R22.1, U1.8 (VSSA), U1.23 (VSS_1), U1.35 (VSS_2), U1.47 (VSS_3), U2.16 (GND), U3.8 (COM), U4.1 (GND)
GPIO_Input_A: CN5.5, CN6.6, U1.2 (PC13-TAMPER-RTC)
GPIO_Input_B: CN5.6, CN6.7, U1.3 (PC14-OSC32_IN)
GPIO_Input_C: CN6.8, U1.4 (PC15-OSC32_OUT)
GPIO_Input_CS: CN1.4, U1.20 (PB2)
I2C1_SCL: CN5.4, U1.45 (PB8)
I2C1_SDA: CN5.3, U1.46 (PB9)
NRST: C20.2, CN1.6, U1.7 (NRST)
unnamed: LED1.3 (B-), R13.2
unnamed: LED1.4 (G-), R12.2
unnamed: LED1.1 (R-), R14.1
OUT1: C1.1, CN3.6, R1.2, U2.4 (IN+1), U3.18 (VS1)
OUT2: C2.1, CN3.7, R2.2, U2.7 (IN±2), U3.15 (VS2)
OUT3: C3.1, CN3.8, R3.2, U2.15 (IN+3), U3.12 (VS3)
SHUNT1: Q1.1 (S), Q1.2 (S), Q1.3 (S), Q2.5 (D), Q2.6 (D), Q2.7 (D), Q2.8 (D), R1.1, U2.3 (IN±1)
SHUNT2: Q3.1 (S), Q3.2 (S), Q3.3 (S), Q4.5 (D), Q4.6 (D), Q4.7 (D), Q4.8 (D), R2.1, U2.6 (IN+2)
SHUNT3: Q5.1 (S), Q5.2 (S), Q5.3 (S), Q6.5 (D), Q6.6 (D), Q6.7 (D), Q6.8 (D), R3.1, U2.14 (IN±3)
SPI2MISO: CN2.4, U1.27 (PB14)
SPI2_MOSI: CN2.3, U1.28 (PB15)
SPI2_NSS: CN2.6, U1.25 (PB12)
SPI2_SCK: CN2.5, U1.26 (PB13)
SYS_JTCK-SWCLK: CN6.4, U1.37 (PA14)
SYS_JTDI: CN6.3, U1.38 (PA15)
SYS_JTDO-TRACESWO: CN6.2, U1.39 (PB3)
SYS_JTMS-SWDIO: CN6.5, U1.34 (PA13)
TIM1_CH1: U1.29 (PA8), U3.1 (HIN1)
TIM1_CH1N: U1.17 (PA7), U3.4 (LIN1)
TIM1_CH2: U1.30 (PA9), U3.2 (HIN2)
TIM1_CH2N: U1.18 (PB0), U3.5 (LIN2)
TIM1_CH3: U1.31 (PA10), U3.3 (HIN3)
TIM1_CH3N: U1.19 (PB1), U3.6 (LIN3)
TIM2_CH1/H1: CN3.1, U1.10 (PA0-WKUP)
TIM2_CH2/H2: CN3.2, U1.11 (PA1)
TIM2_CH3/H3: CN3.3, U1.21 (PB10)
TIM2_CH4: R12.1, U1.22 (PB11)
TIM3_CH1: R13.1, U1.40 (PB4)
TIM3_CH2: R14.2, U1.41 (PB5)
USART1_RX: CN1.3, U1.43 (PB7)
USART1_TX: CN1.2, U1.42 (PB6)
USB_D+: CN4.3 (D+), R11.1, U1.33 (PA12)
USB_D-: CN4.2 (D-), U1.32 (PA11)

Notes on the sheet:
Datasheet tells us to protect against parasitic resets.
Ferrite bead filtering from USB 5V line.
Additional serial FPC connector
Analog low pass filter.
Motor IDC connector (matches motor pins)
Gate driver
Micro USB
Voltage divider from a maximum of 24V for this board.
Phase U
Power regulator and filtering
Power caps
CL ~= 2 * (Cload - Cstray)
MCU decoupling caps
Voltage dividider at half point of analog voltage range for the shunt amplifier. Run to a spare input so we can measure the ref.
Connectors
Phase V
Power and control, FPC connector
Phase W
Current sense amplifier
Pin names copied from STM32CubeIDE as configured for this project.
Alternative power connections.

Board: 4 copper layers, 65 parts (17 on the bottom side), 69 nets, no tracks yet.

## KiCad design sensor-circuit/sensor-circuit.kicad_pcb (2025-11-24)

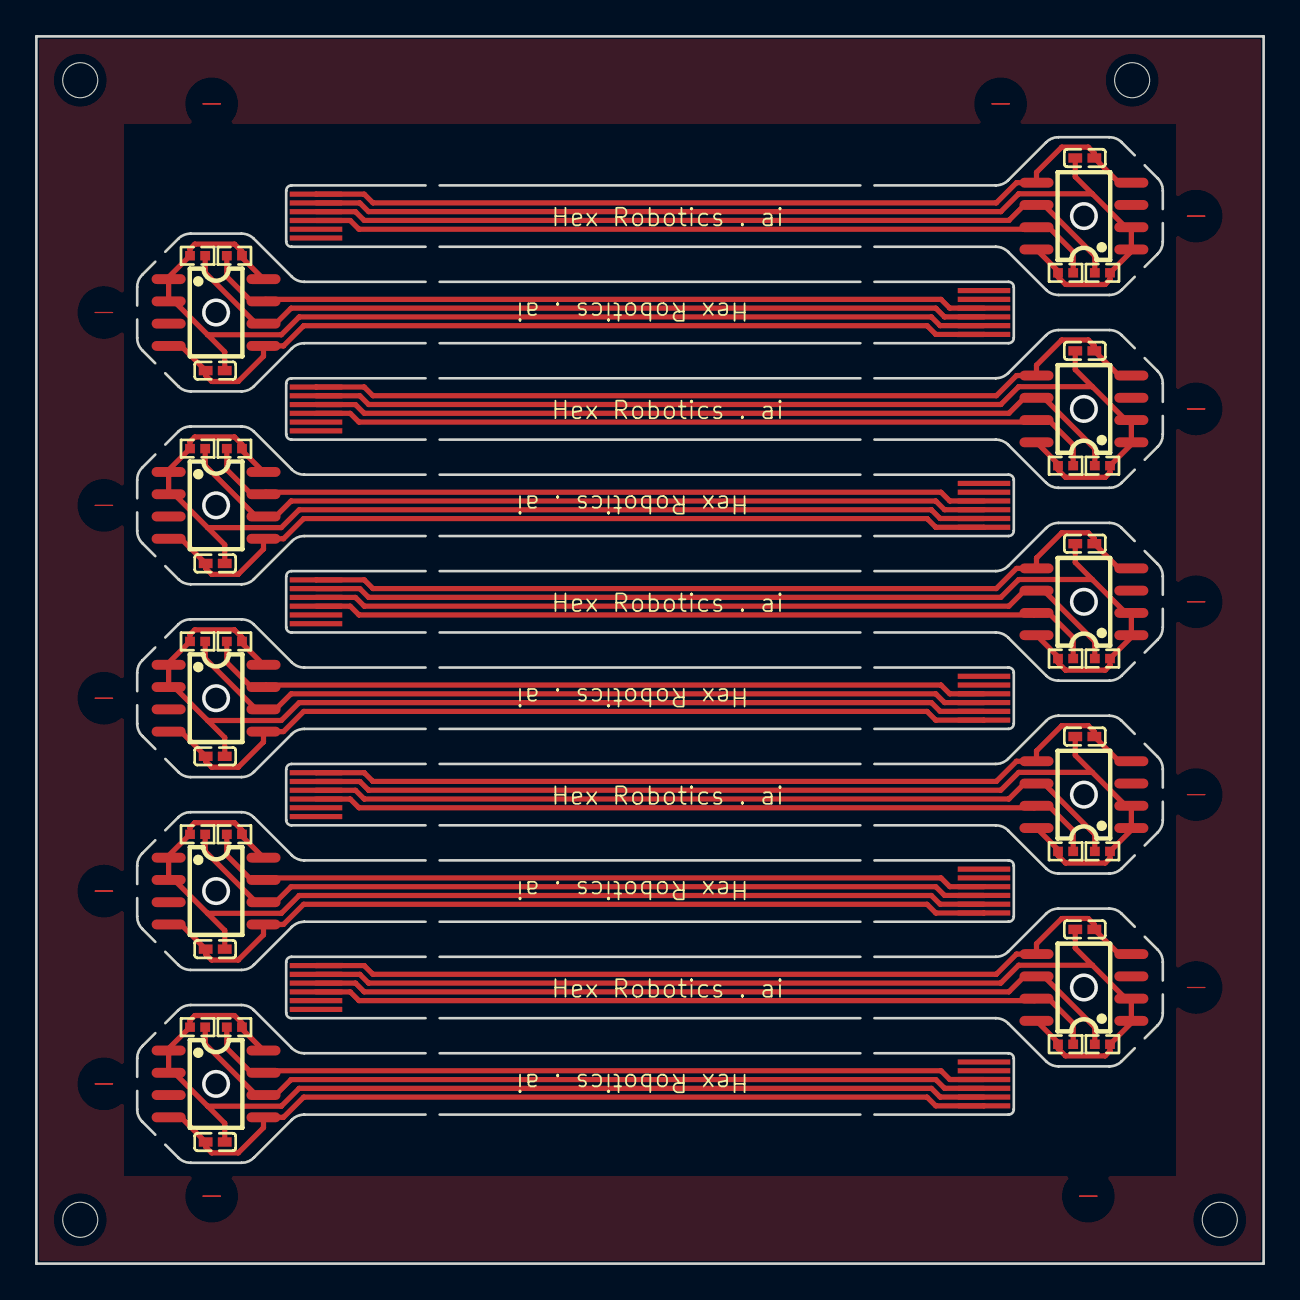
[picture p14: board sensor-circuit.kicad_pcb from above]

Board: 2 copper layers, 70.0 x 70.0 mm, 50 parts (0 on the bottom side), 40 nets.

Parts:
C1, C2, C3, C4, C5, C6, C7, C8, C9, C10: 100nF; C0402
FPC1, FPC2, FPC3, FPC4, FPC5, FPC6, FPC7, FPC8, FPC9, FPC10: FPC-6P-P0.50-Pattern
R1, R2, R3, R4, R5, R6, R7, R8, R9, R10, R11, R12, R13, R14, R15, R16, R17, R18, R19, R20: 10kΩ; R0402
U1, U2, U3, U4, U5, U6, U7, U8, U9, U10: SOIC-8_L5.0-W4.0-P1.27-LS6.0-BL

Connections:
/sensor-circuit-singlet1/3V3: C2.2, FPC2.5, R3.2, R4.2, U2.1 (VDD5V), U2.2 (VDD3V3), U2.8 (DIR)
/sensor-circuit-singlet1/GND: C2.1, FPC2.6, U2.4 (GND), U2.5 (PGO)
/sensor-circuit-singlet1/SCL: FPC2.3, R3.1, U2.7 (SCL)
/sensor-circuit-singlet1/SDA: FPC2.4, R4.1, U2.6 (SDA)
/sensor-circuit-singlet2/3V3: C3.2, FPC3.5, R5.2, R6.2, U3.1 (VDD5V), U3.2 (VDD3V3), U3.8 (DIR)
/sensor-circuit-singlet2/GND: C3.1, FPC3.6, U3.4 (GND), U3.5 (PGO)
/sensor-circuit-singlet2/SCL: FPC3.3, R5.1, U3.7 (SCL)
/sensor-circuit-singlet2/SDA: FPC3.4, R6.1, U3.6 (SDA)
/sensor-circuit-singlet3/3V3: C4.2, FPC4.5, R7.2, R8.2, U4.1 (VDD5V), U4.2 (VDD3V3), U4.8 (DIR)
/sensor-circuit-singlet3/GND: C4.1, FPC4.6, U4.4 (GND), U4.5 (PGO)
/sensor-circuit-singlet3/SCL: FPC4.3, R7.1, U4.7 (SCL)
/sensor-circuit-singlet3/SDA: FPC4.4, R8.1, U4.6 (SDA)
/sensor-circuit-singlet4/3V3: C5.2, FPC5.5, R9.2, R10.2, U5.1 (VDD5V), U5.2 (VDD3V3), U5.8 (DIR)
/sensor-circuit-singlet4/GND: C5.1, FPC5.6, U5.4 (GND), U5.5 (PGO)
/sensor-circuit-singlet4/SCL: FPC5.3, R9.1, U5.7 (SCL)
/sensor-circuit-singlet4/SDA: FPC5.4, R10.1, U5.6 (SDA)
/sensor-circuit-singlet5/3V3: C6.2, FPC6.5, R11.2, R12.2, U6.1 (VDD5V), U6.2 (VDD3V3), U6.8 (DIR)
/sensor-circuit-singlet5/GND: C6.1, FPC6.6, U6.4 (GND), U6.5 (PGO)
/sensor-circuit-singlet5/SCL: FPC6.3, R11.1, U6.7 (SCL)
/sensor-circuit-singlet5/SDA: FPC6.4, R12.1, U6.6 (SDA)
/sensor-circuit-singlet6/3V3: C7.2, FPC7.5, R13.2, R14.2, U7.1 (VDD5V), U7.2 (VDD3V3), U7.8 (DIR)
/sensor-circuit-singlet6/GND: C7.1, FPC7.6, U7.4 (GND), U7.5 (PGO)
/sensor-circuit-singlet6/SCL: FPC7.3, R13.1, U7.7 (SCL)
/sensor-circuit-singlet6/SDA: FPC7.4, R14.1, U7.6 (SDA)
/sensor-circuit-singlet7/3V3: C8.2, FPC8.5, R15.2, R16.2, U8.1 (VDD5V), U8.2 (VDD3V3), U8.8 (DIR)
/sensor-circuit-singlet7/GND: C8.1, FPC8.6, U8.4 (GND), U8.5 (PGO)
/sensor-circuit-singlet7/SCL: FPC8.3, R15.1, U8.7 (SCL)
/sensor-circuit-singlet7/SDA: FPC8.4, R16.1, U8.6 (SDA)
/sensor-circuit-singlet8/3V3: C9.2, FPC9.5, R17.2, R18.2, U9.1 (VDD5V), U9.2 (VDD3V3), U9.8 (DIR)
/sensor-circuit-singlet8/GND: C9.1, FPC9.6, U9.4 (GND), U9.5 (PGO)
/sensor-circuit-singlet8/SCL: FPC9.3, R17.1, U9.7 (SCL)
/sensor-circuit-singlet8/SDA: FPC9.4, R18.1, U9.6 (SDA)
/sensor-circuit-singlet9/3V3: C10.2, FPC10.5, R19.2, R20.2, U10.1 (VDD5V), U10.2 (VDD3V3), U10.8 (DIR)
/sensor-circuit-singlet9/GND: C10.1, FPC10.6, U10.4 (GND), U10.5 (PGO)
/sensor-circuit-singlet9/SCL: FPC10.3, R19.1, U10.7 (SCL)
/sensor-circuit-singlet9/SDA: FPC10.4, R20.1, U10.6 (SDA)
/sensor-circuit-singlet/3V3: C1.2, FPC1.5, R1.2, R2.2, U1.1 (VDD5V), U1.2 (VDD3V3), U1.8 (DIR)
/sensor-circuit-singlet/GND: C1.1, FPC1.6, U1.4 (GND), U1.5 (PGO)
/sensor-circuit-singlet/SCL: FPC1.3, R1.1, U1.7 (SCL)
/sensor-circuit-singlet/SDA: FPC1.4, R2.1, U1.6 (SDA)

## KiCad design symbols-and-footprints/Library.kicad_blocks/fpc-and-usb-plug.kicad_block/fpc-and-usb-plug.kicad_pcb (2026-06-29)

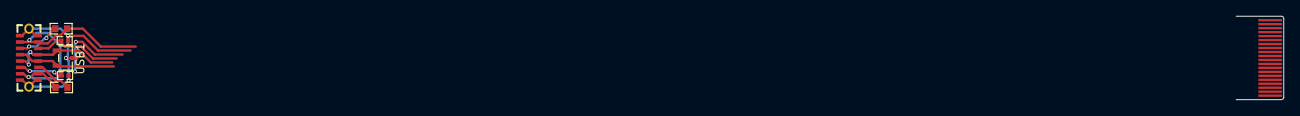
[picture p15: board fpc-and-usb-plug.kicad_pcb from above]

Board: 2 copper layers, 7 parts (0 on the bottom side), 9 nets.

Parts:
D12: SOT-23-3_L3.0-W1.7-P0.95-LS2.9-BR
FPC1: FPC-20P-P0.50-Pattern
R17, R76: 56kΩ; R0603
R96, R103: 1MΩ; R0402
USB1: USB-C-SMD_TC-005

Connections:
/servo-usb-connector/CC1x: R76.1, USB1.A5 (CC1)
/servo-usb-connector/CC2x: R17.1, USB1.B5 (CC2)
/servo-usb-connector/VBUSx: R17.2, R76.2, USB1.A4 (VBUS), USB1.A9 (VBUS), USB1.B4 (VBUS), USB1.B9 (VBUS)
GND: D12.3 (K), FPC1.1, FPC1.2, FPC1.3, FPC1.4, FPC1.5, FPC1.6, FPC1.7, FPC1.8, FPC1.9, FPC1.10, R96.1, R103.1, USB1.1 (EH), USB1.2 (EH), USB1.A1 (GND), USB1.A12 (GND), USB1.B1 (GND), USB1.B12 (GND)
SERVO1_BOOT0: R96.2, USB1.A8 (SUB1)
SERVO1_NRST: R103.2, USB1.B8 (SUB2)
USBDN1_D+: D12.2 (A1), USB1.A6 (DP1), USB1.B6 (DP2)
USBDN1_D-: D12.1 (A1), USB1.A7 (DN1), USB1.B7 (DN2)
VCC: FPC1.11, FPC1.12, FPC1.13, FPC1.14, FPC1.15, FPC1.16, FPC1.17, FPC1.18, FPC1.19, FPC1.20

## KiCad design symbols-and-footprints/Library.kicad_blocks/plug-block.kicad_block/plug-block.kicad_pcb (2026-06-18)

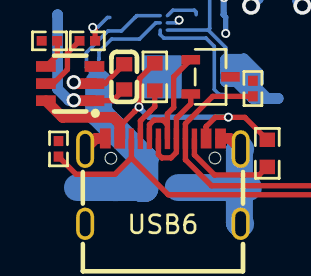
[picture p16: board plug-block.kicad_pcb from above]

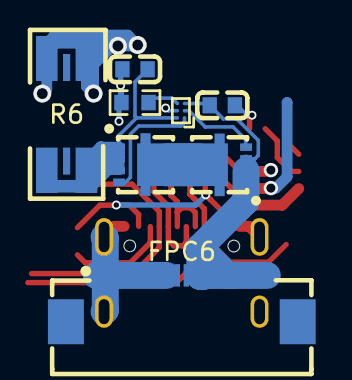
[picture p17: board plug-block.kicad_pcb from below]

Board: 4 copper layers, 18 parts (8 on the bottom side), 17 nets.

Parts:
C40, C80, C81: 1uF; C0603
D11: SOT-23-3_L3.0-W1.7-P0.95-LS2.9-BR
FPC6: FPC-SMD_20P-P0.50_XUNPU_FPC-05F-20PH20
Q19, Q20: WDFN-5_L3.1-W3.1-P0.65-BL_1
R6: 5mΩ; R2512 Shunt with Kelvin connections
R70: 20kΩ; R0402
R71, R89: 56kΩ; R0603
R75: 10kΩ; R0603
R91: 100kΩ; R0402
R101, R108: 1MΩ; R0402
U31: WLCSP-6_L1.2-W0.8-P0.40-TL
U32: SOT-23-6_L2.9-W1.6-P0.95-LS2.8-BR
USB6: USB-C-SMD_TYPE-C16PIN

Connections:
5V: C40.2, U32.1 (IN)
/servo-usb-connector5/CC1x: R71.2, USB6.A5 (CC1)
/servo-usb-connector5/CC2x: R89.1, USB6.B5 (CC2)
/servo-usb-connector5/ILIMx: R70.2, U32.5 (ILIM)
/servo-usb-connector5/VBUSx: R71.1, R89.2, U32.6 (OUT), USB6.A4B9 (VBUS), USB6.B4A9 (VBUS)
/servo-usb-connector5/VCCx: C80.2, FPC6.11, FPC6.12, FPC6.13, FPC6.14, FPC6.15, FPC6.16, FPC6.17, FPC6.18, FPC6.19, FPC6.20, Q19.1 (S), Q19.2 (S), Q19.3 (S), U31.C1 (VOUT)
/servo-usb-connector5/back-to-back-mosfets3/GATE1x: Q20.4 (G), U31.A1 (VGATE1)
/servo-usb-connector5/back-to-back-mosfets3/GATE2x: Q19.4 (G), U31.B1 (VGATE2)
/servo-usb-connector5/back-to-back-mosfets3/Mid-MOSFETSx: Q19.5 (D), Q20.5 (D)
/servo-usb-connector5/back-to-back-mosfets3/VIN: C81.2, Q20.1 (S), Q20.2 (S), Q20.3 (S), R6.1 (Shunt-1), U31.A2 (VIN)
CONNECTx: R75.2, U31.C2 (VCT)
GND: C40.1, C80.1, C81.1, D11.3 (K), FPC6.1, FPC6.2, FPC6.3, FPC6.4, FPC6.5, FPC6.6, FPC6.7, FPC6.8, FPC6.9, FPC6.10, R70.1, R75.1, R101.1, R108.1, U31.B2 (GND), U32.2 (GND), USB6.1 (SHELL), USB6.2 (SHELL), USB6.3 (SHELL), USB6.4 (SHELL), USB6.A1B12 (GND), USB6.B1A12 (GND)
SERVO6_BOOT0: R108.2, USB6.A8 (SBU1)
SERVO6_NRST: R101.2, USB6.B8 (SBU2)
USBDN6_D+: D11.2 (A1), USB6.A6 (DP1), USB6.B6 (DP2)
USBDN6_D-: D11.1 (A1), USB6.A7 (DN1), USB6.B7 (DN2)
nOCS6: R91.2, U32.4 (/FAULT)

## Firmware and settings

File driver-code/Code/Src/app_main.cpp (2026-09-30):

#include "app_main.hpp"

#include "interrupts.hpp"
#include "io.hpp"
#include "usb_com.hpp"
#include "test_schedules.hpp"
#include "parameters_store.hpp"
#include "math_utils.hpp"
#include "constants.hpp"

#include <stm32g4xx_hal.h>
#include <stm32g4xx_ll_cordic.h>


// Keep track of how many readouts we see.
uint16_t last_readout_number = 0;

// Main loop stats tracking
// ------------------------
uint32_t main_loop_number = 0;
uint32_t timing_loop_number = 0;
uint16_t timing_readout_number = 0;


const uint32_t min_timing_period_millis = 50;
uint32_t last_update_time_millis = 0;

float main_loop_rate = 0.0f;
float adc_update_rate = 0.0f;



// Calibration tracking
// --------------------

enum struct CalibrationMode {
  NONE,
  RESISTANCE,
  INDUCTANCE,
  ROTATING_CHIRP,
  FIXED_CHIRP
};

CalibrationMode calibration_mode = CalibrationMode::NONE;


// Communication buffers and state
// -------------------------------

const uint32_t partial_message_timeout_ms = 500;
const uint32_t sending_timeout_ms = 500;

hex_mini_drive::ConsistentOverheadByteStuffing<hex_mini_drive::MAX_MESSAGE_SIZE> encoding_buffer = {};

// Time of last USB packet sent; used to detect timeouts.
uint32_t last_send_time = 0;

// Time of the last USB packet received; used to detect timeouts.
uint32_t last_receive_time = 0;

// Number of bytes discarded due to invalid messages.
uint32_t bytes_discarded = 0;

uint32_t bytes_sent = 0;

uint16_t stream_state = 0;
uint16_t stream_last_sent = 0;
size_t readouts_to_send = 0;
size_t readouts_sent = 0;
bool reply_current_calibration = false;
bool reply_control_parameters = false;
bool reply_unit_test = false;
bool reply_saved_to_flash = false;

UnitTestFunction unit_test_function = nullptr;



// Initialization
// --------------


void app_init() {

  // Setup the CORDIC engine to compute atan2 using 32bit parameters.
  LL_CORDIC_Config(
    CORDIC, 
    LL_CORDIC_FUNCTION_PHASE,     // Calculates phase and magnitude
    LL_CORDIC_PRECISION_6CYCLES,   // Balance of precision vs execution speed
    LL_CORDIC_SCALE_0,            // Scale factor 0 (Input bounds: [-1, 1])
    LL_CORDIC_NBWRITE_2,          // Expecting 2 writes: X then Y
    LL_CORDIC_NBREAD_2,           // Yields 2 reads: Phase then Magnitude
    LL_CORDIC_INSIZE_32BITS,       // 32-bit Q1.31 fixed-point input
    LL_CORDIC_OUTSIZE_32BITS     // 32-bit Q1.31 fixed-point output
  );
  
  io_init();

  set_GREEN_LED(0xFF);

  usb_init();
}



// Communications and commands
// ---------------------------


// Start an active test of the motor.
void motor_start_test(PWMSchedule const& schedule, float value, bool take_snapshot) {
  // Clear the readouts buffer of old data.
  readout_history_mark_reset();
  readouts_to_send = take_snapshot ? hex_mini_drive::HISTORY_SIZE : 0;
  readouts_sent = 0;

  // Start the test schedule.
  set_motor_command(DriverState{ 
    .mode = DriverMode::SCHEDULE,
    .target = value,
    .schedule = DriveSchedule{ .pointer = &schedule },
  });
}

// Run a unit test that takes a function pointer to a test function (which itself takes a buffer); returns whether error occurred.
bool run_unit_test(UnitTestFunction test_function) {
  if (reply_unit_test) return true; // We are already running a unit test.

  // Remember which test to run when the USB queue is ready.
  unit_test_function = test_function;

  // Set the flag to indicate that we have a unit test result ready to send.
  reply_unit_test = true;

  return false;
}


// Handle the command on the buffer; returns whether there was an error.
void handle_message(hex_mini_drive::Message const& message) {

  using namespace hex_mini_drive;

  switch (message.message_code) {
    case NULL_MESSAGE_CODE:
      // No command received; ignore it.
      return;

    case STREAM_FULL_READOUTS: {
      // Continuously stream data if timeout > 0.
      stream_state = std::get<StreamFullReadouts>(message.message_data).stream_state;
      // Also stop the motor if we stop the stream.
      if (not stream_state) set_motor_command(DriverState{.mode = DriverMode::OFF});
      return;
    }
    case GET_READOUTS_SNAPSHOT: {
      // Cancel streaming; so we can take a data snapshot without interruptions.
      stream_state = 0;
      
      // Reply with the full history.
      readout_history_mark_reset();
      readouts_to_send = hex_mini_drive::HISTORY_SIZE;
      readouts_sent = 0;

      // Ping the driver loop to reset the history.
      set_motor_command(DriverState{.mode = DriverMode::CONTINUE});


      return;
    }
    // Turn off the motor driver.
    case SET_STATE_OFF: {
      // Repeat command, with the interrupt guards.
      set_motor_command(DriverState{.mode = DriverMode::OFF});
      return;
    }
        
    // Measure the motor phase currents.
    
    case SET_STATE_TEST_ALL_PERMUTATIONS:
      motor_start_test(
        test_all_permutations, 
        std::get<TestCommand>(message.message_data).pwm_value, 
        std::get<TestCommand>(message.message_data).take_snapshot > 0
      );
      return;
    case SET_STATE_TEST_GROUND_SHORT:
      motor_start_test(
        test_ground_short, 
        std::get<TestCommand>(message.message_data).pwm_value, 
        std::get<TestCommand>(message.message_data).take_snapshot > 0
      );
      return;
    case SET_STATE_TEST_POSITIVE_SHORT:
      motor_start_test(
        test_positive_short, 
        std::get<TestCommand>(message.message_data).pwm_value, 
        std::get<TestCommand>(message.message_data).take_snapshot > 0
      );
      return;

    // Drive the motor.
    case SET_STATE_DRIVE_6_SECTOR: {
      set_motor_command(DriverState{ 
        .mode = DriverMode::DRIVE_6_SECTOR, 
        .duration = std::get<BasicDriveCommand>(message.message_data).timeout, 
        .active_pwm = std::get<BasicDriveCommand>(message.message_data).pwm_value * control_parameters.motor_direction,
      });
      return;
    }

    case SET_STATE_DRIVE_PERIODIC: {
      set_motor_command(DriverState{
        .mode = DriverMode::DRIVE_PERIODIC, 
        .duration = std::get<SetStateDrivePeriodic>(message.message_data).timeout,
        .active_angle = std::get<SetStateDrivePeriodic>(message.message_data).angle,
        .active_pwm = std::get<SetStateDrivePeriodic>(message.message_data).pwm_value,
        .target = std::get<SetStateDrivePeriodic>(message.message_data).angular_speed * control_parameters.motor_direction,
      });
      return;
    }

    case SET_STATE_DRIVE_SMOOTH: {
      set_motor_command(DriverState{
        .mode = DriverMode::DRIVE_SMOOTH, 
        .duration = std::get<SetStateDriveSmooth>(message.message_data).timeout,
        .target_pwm = std::get<SetStateDriveSmooth>(message.message_data).pwm_value * control_parameters.motor_direction,
      });
      return;
    }

    case SET_STATE_DRIVE_TORQUE: {
      set_motor_command(DriverState{
        .mode = DriverMode::DRIVE_TORQUE, 
        .duration = std::get<SetStateDriveTorque>(message.message_data).timeout,
        .target = std::get<SetStateDriveTorque>(message.message_data).target_current * control_parameters.motor_direction,
      });
      return;
    }

    case SET_STATE_DRIVE_BATTERY_POWER: {
      set_motor_command(DriverState{
        .mode = DriverMode::DRIVE_BATTERY_POWER, 
        .duration = std::get<SetStateDriveBatteryPower>(message.message_data).timeout,
        .target = std::get<SetStateDriveBatteryPower>(message.message_data).target_power * control_parameters.motor_direction,
      });
      return;
    }

    case SET_STATE_DRIVE_SPEED: {
      set_motor_command(DriverState{
        .mode = DriverMode::DRIVE_SPEED, 
        .duration = std::get<SetStateDriveSpeed>(message.message_data).timeout,
        .target = std::get<SetStateDriveSpeed>(message.message_data).target_speed * control_parameters.motor_direction,
      });
      return;
    }

    case SET_STATE_DRIVE_TORQUE_SPEED: {
      set_motor_command(DriverState{
        .mode = DriverMode::DRIVE_TORQUE_SPEED, 
        .duration = std::get<SetStateDriveTorqueSpeed>(message.message_data).timeout,
        .current_target = std::get<SetStateDriveTorqueSpeed>(message.message_data).target_current * control_parameters.motor_direction,
        .speed_target = std::get<SetStateDriveTorqueSpeed>(message.message_data).target_speed * control_parameters.motor_direction,
      });
      return;
    }

    case SET_STATE_SEEK_ANGLE: {
      set_motor_command(DriverState{
        .mode = DriverMode::SEEK_ANGLE, 
        .duration = std::get<SetStateSeekAngle>(message.message_data).timeout,
        .speed_target = std::get<SetStateSeekAngle>(message.message_data).target_speed * control_parameters.motor_direction,
        .target = std::get<SetStateSeekAngle>(message.message_data).target_current * control_parameters.motor_direction,
        .seek_angle = SeekAngle{
          .target_angle = std::get<SetStateSeekAngle>(message.message_data).target_angle * control_parameters.motor_direction,
          .target_rotation = std::get<SetStateSeekAngle>(message.message_data).target_rotation * control_parameters.motor_direction,
        }
      });
      return;
    }

    // Freewheel the motor.
    case SET_STATE_FREEWHEEL:
      set_motor_command(DriverState{ .mode = DriverMode::FREEWHEEL });
      return;

    case SET_CURRENT_CALIBRATION:
      current_calibration = std::get<CurrentCalibration>(message.message_data);
      reset_calibration_variables();
      reply_current_calibration = true;
      return;
        
    case RESET_CURRENT_CALIBRATION:
      // Reset the current factors to the default values.
      current_calibration = default_current_calibration;
      reset_calibration_variables();
      reply_current_calibration = true;
      return;

    case SET_CONTROL_PARAMETERS:
      control_parameters = std::get<ControlParameters>(message.message_data);
      reply_control_parameters = true;
      return;

    case RESET_CONTROL_PARAMETERS:
      control_parameters = default_control_parameters;
      reply_control_parameters = true;
      return;

    case GET_CURRENT_CALIBRATION:
      reply_current_calibration = true;
      return;

    case GET_CONTROL_PARAMETERS:
      reply_control_parameters = true;
      return;

    case SET_ANGLE: {
      set_angle(std::get<SetAngle>(message.message_data).angle);
      return;
    }

    case SET_ROTATIONS: {
      set_rotations(std::get<SetRotations>(message.message_data).rotations);
      return;
    }

    case SAVE_SETTINGS_TO_FLASH:
      if(is_motor_safed()){
        save_settings_to_flash(current_calibration, control_parameters);

        current_calibration = get_current_calibration();
        control_parameters = get_control_parameters();
        
        reply_saved_to_flash = true;
        return;
      }

    // We shouldn't receive these messages; the driver only sends them.
    case SETTINGS_SAVED_TO_FLASH:
    case CURRENT_CALIBRATION:
    case CONTROL_PARAMETERS:
    case READOUT:
    case FULL_READOUT:
    case UNIT_TEST_OUTPUT:
      return;

    
    case SET_STATE_RESISTANCE_CALIBRATION: {
      calibration_mode = CalibrationMode::RESISTANCE;
      
      // Clear the readouts buffer of old data.
      readout_history_mark_reset();
      readouts_to_send = (std::get<TestCommand>(message.message_data).take_snapshot > 0) ? hex_mini_drive::HISTORY_SIZE : 0;
      readouts_sent = 0;

      set_motor_command(DriverState{
        .mode = DriverMode::RESISTANCE_CALIBRATION,
        .duration = hex_mini_drive::HISTORY_SIZE,
        .target = clip_to(0.0f, pwm_max, std::get<TestCommand>(message.message_data).pwm_value),
      });
      return;
    }

    case SET_STATE_INDUCTANCE_CALIBRATION: {
      calibration_mode = CalibrationMode::INDUCTANCE;

      // Clear the readouts buffer of old data.
      readout_history_mark_reset();
      readouts_to_send = (std::get<TestCommand>(message.message_data).take_snapshot > 0) ? hex_mini_drive::HISTORY_SIZE : 0;
      readouts_sent = 0;
      
      set_motor_command(DriverState{
        .mode = DriverMode::INDUCTANCE_CALIBRATION,
        .duration = hex_mini_drive::HISTORY_SIZE,
        .target = clip_to(0.0f, pwm_max, std::get<TestCommand>(message.message_data).pwm_value),
      });
      return;
    }

    case SET_STATE_ROTATING_CALIBRATION_CHIRP: {
      calibration_mode = CalibrationMode::ROTATING_CHIRP;
      // Clear the readouts buffer of old data.
      readout_history_mark_reset();
      readouts_to_send = (std::get<TestCommand>(message.message_data).take_snapshot > 0) ? hex_mini_drive::HISTORY_SIZE : 0;
      readouts_sent = 0;

      set_motor_command(DriverState{
        .mode = DriverMode::ROTATING_CALIBRATION_CHIRP,
        .duration = hex_mini_drive::HISTORY_SIZE,
        .target = clip_to(0.0f, pwm_max, std::get<TestCommand>(message.message_data).pwm_value),
        .test_parameters = TestParameters{
          .test_speed = std::get<TestCommand>(message.message_data).test_speed,
          .test_duration = std::get<TestCommand>(message.message_data).test_duration,
        },
      });
      return;
    }
    case SET_STATE_FIXED_CALIBRATION_CHIRP: {
      calibration_mode = CalibrationMode::FIXED_CHIRP;
      
      readout_history_mark_reset();
      readouts_to_send = (std::get<TestCommand>(message.message_data).take_snapshot > 0) ? hex_mini_drive::HISTORY_SIZE : 0;
      readouts_sent = 0;


      set_motor_command(DriverState{
        .mode = DriverMode::FIXED_CALIBRATION_CHIRP,
        .duration = hex_mini_drive::HISTORY_SIZE,
        .active_angle = 0,
        .target = clip_to(0.0f, pwm_max, std::get<TestCommand>(message.message_data).pwm_value),
        .test_parameters = TestParameters{
          .test_speed = std::get<TestCommand>(message.message_data).test_speed,
          .test_duration = std::get<TestCommand>(message.message_data).test_duration,
          .test_angle = std::get<TestCommand>(message.message_data).test_angle
        },
      });
      return;
    }
    case SET_STATE_HFI_SALIENCY_PULSES: {
      // Clear the readouts buffer of old data.
      readout_history_mark_reset();
      readouts_to_send = (std::get<TestCommand>(message.message_data).take_snapshot > 0) ? hex_mini_drive::HISTORY_SIZE : 0;
      readouts_sent = 0;
      
      set_motor_command(DriverState{
        .mode = DriverMode::HFI_SALIENCY_PULSES,
        .duration = std::get<TestCommand>(message.message_data).test_duration,
        .target = clip_to(0.0f, pwm_max, std::get<TestCommand>(message.message_data).pwm_value),
      });
      return;
    }
  }
}

void reset_buffers(){
  set_motor_command(DriverState{.mode = DriverMode::OFF});

  encoding_buffer.encode_reset();
  encoding_buffer.decode_reset();
  last_receive_time = 0;
  stream_state = 0;
}


void serialize_message(hex_mini_drive::Message const& message) {
  uint8_t out_buffer[hex_mini_drive::MAX_MESSAGE_SIZE] = {0};
  size_t out_buffer_size = hex_mini_drive::write_message(out_buffer, hex_mini_drive::MAX_MESSAGE_SIZE, message);

  if (out_buffer_size) encoding_buffer.encode_message(out_buffer, out_buffer_size);
}

void queue_response(hex_mini_drive::FullReadout const& readout) {
  // Wait until the previous message has been sent or buffers reset before encoding a new message.
  if (encoding_buffer.is_message_encoded()) return;

  // Queue the readout history to the send buffer.
  if(readouts_to_send > 0){
    const bool reset_ongoing = readout_history_get_reset_flag();
    const bool waiting_for_data = get_readout_history_size() < readouts_to_send;
    
    // Wait until we filled the buffer before sending readouts, to avoid interfering with the ADC loop.
    if (reset_ongoing or waiting_for_data) return;

    serialize_message(hex_mini_drive::Message{
      .message_code = hex_mini_drive::MessageCode::READOUT,
      .message_data = get_readout_history()[readouts_sent]
    });
    
    // Readout added to the USB buffer.
    readouts_sent += 1;

    if (readouts_sent >= readouts_to_send) {
      // We have sent all the readouts; reset the counters.
      readouts_to_send = 0;
      readouts_sent = 0;
    }

    return;
  }

  // Stream readouts but only once per readout number.
  if(stream_state and stream_last_sent != readout.readout_number){
    serialize_message(hex_mini_drive::Message{
      .message_code = hex_mini_drive::MessageCode::FULL_READOUT,
      .message_data = readout
    });

    stream_last_sent = readout.readout_number;
    return;
  }

  // Send unit test response if requested.
  if (reply_unit_test) {
    hex_mini_drive::Message message = {
      .message_code = hex_mini_drive::MessageCode::UNIT_TEST_OUTPUT,
      .message_data = hex_mini_drive::UnitTestOutput{}
    };
    unit_test_function(
      reinterpret_cast<char*>(std::get<hex_mini_drive::UnitTestOutput>(message.message_data).data()), 
      hex_mini_drive::UNIT_TEST_OUTPUT_SIZE
    );
    serialize_message(message);
    reply_unit_test = false;
    return;
  }

  // Send control parameters if requested.
  if (reply_control_parameters) {
    serialize_message(hex_mini_drive::Message{
      .message_code = hex_mini_drive::MessageCode::CONTROL_PARAMETERS,
      .message_data = control_parameters
    });
    reply_control_parameters = false;
    return;
  }

  // Send current factors if requested.
  if (reply_current_calibration) {
    serialize_message(hex_mini_drive::Message{
      .message_code = hex_mini_drive::MessageCode::CURRENT_CALIBRATION,
      .message_data = current_calibration
    });
    reply_current_calibration = false;
    return;
  }

  if (reply_saved_to_flash) {
    serialize_message(hex_mini_drive::Message{
      .message_code = hex_mini_drive::MessageCode::SETTINGS_SAVED_TO_FLASH,
    });
    reply_saved_to_flash = false;
    return;
  }
}

void receive_data(uint8_t * rx_buffer, size_t rx_size) {
  // We have a partial message that has timed out; reset the buffer and continue 
  // reading as a fresh message.
  if (encoding_buffer.decode_ongoing() and 
    (HAL_GetTick() - last_receive_time) > partial_message_timeout_ms) {
    reset_buffers();
  }

  encoding_buffer.decode_chunk(rx_buffer, rx_size, [&](uint8_t * buffer, size_t size){
    hex_mini_drive::Message message;
    if(hex_mini_drive::read_message(message, buffer, size)){
      // We have a valid message; handle it.
      handle_message(message);
    } else {
      // Invalid message; ignore it.
      bytes_discarded += size;
    }
  });
  last_receive_time = HAL_GetTick();
}

void comms_update(hex_mini_drive::FullReadout const& readout) {
  // Queue the state readouts on the USB buffer.
  queue_response(readout);

  const bool update_success = usb_update(
    encoding_buffer.encoding_buffer, encoding_buffer.encoding_buffer_size, 
    [&](uint8_t * buffer, size_t size){
      receive_data(buffer, size);
    }
  );

  if (update_success) {
    bytes_sent += encoding_buffer.encoding_buffer_size;

    // Data was queued; clear the response buffer.
    encoding_buffer.encode_reset();
    last_send_time = HAL_GetTick();
  } else if (encoding_buffer.is_message_encoded()) {
    // We have data to send but the queue is busy.
    if(HAL_GetTick() - last_send_time > sending_timeout_ms){
      // Timeout waiting for send; reset the buffers.
      reset_buffers();

      return usb_reset();
    }
  }
}

// Main app loop
// -------------
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

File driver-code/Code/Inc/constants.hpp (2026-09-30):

#pragma once

#include <cstdint>
#include <cstddef>
#include <cmath>
#include <bit>

#include "type_definitions.hpp"
#include "math_utils.hpp"

#include "hex_mini_drive_interface.hpp"


// Electrical and control limits
// -----------------------------

// 6A max DQ0 driving current.
constexpr float max_drive_current = hex_mini_drive::CURRENT_UNITS_PER_AMP * 6.0;

// Inverse for fast math.
constexpr float max_drive_current_inverse = 1.f / max_drive_current;

// 12W max drive power.
constexpr float max_drive_power = 12.0;

// Inverse for fast math.
constexpr float max_drive_power_inverse = 1.f / max_drive_power;


// Angle base is the max uint32_t + 1, so we need to express it as float: std::pow(2, angle_bit_count).
constexpr float angle_base = 4294967296.f;

// Number of MCU clock ticks per PWM cycle; counting up then down.
constexpr int32_t pwm_period = 2 * hex_mini_drive::PWM_BASE;

// Number of PWM cycles per second.
constexpr int32_t pwm_cycles_per_second = hex_mini_drive::CLOCK_FREQUENCY / pwm_period;

// We define the maximum drive/measurable electrical rotation frequency as slightly less than
// 12 x the sampling rate. At this speed we move 30degrees around the circle per PWM cycle,
// but not exactly 30degrees so we can sample all angles.
constexpr float max_frequency = pwm_cycles_per_second / 11.9f;

// Number of electrical revolutions per mechanical revolution. This is pole pairs times the number of slot triplets.
constexpr float rotor_revolutions_per_electric = 4;

// Maximum speed that we can drive at our PWM cycle/sampling frequency. In motor rotations per minute (RPM).
constexpr float max_rpm = max_frequency * 60.f / rotor_revolutions_per_electric;

// Maximum angular speed we can achieve in our angle units per PWM cycle.
constexpr float max_angular_speed = 1.f * angle_base * max_frequency / static_cast<float>(pwm_cycles_per_second);

// Inverse of the maximum angular speed so we can convert to floating point values without doing a division.
constexpr float max_angular_speed_inverse = 1.f / max_angular_speed;


// Unit definitions
// ----------------


// Inverse of the PWM base so we can convert to floating point values without doing a division.
constexpr float pwm_base_inverse = 1.0f / static_cast<float>(hex_mini_drive::PWM_BASE);

// We need to compute and average of the PWM outputs, so this is useful.
constexpr float half_pwm_base_inverse = 0.5f * pwm_base_inverse;

// The ADC has a 12-bit resolution.
constexpr uint16_t adc_max_value = 0xFFF; // 2^12 - 1 == 4095 == 0xFFF.

// Readout number base; we cycle back to 0 instead of reaching this value.
constexpr int32_t readout_number_base = 1 << 16;

// Base and number of hall sectors.
constexpr uint8_t hall_sector_base = 6;

// Number of significant bits for the angle representation (20 bits so 
// we can multiply with 12 bit parameter values and fit within 32 bits).
constexpr size_t angle_bit_count = 32;

// Number of bits in the sin tables; 12 bits gives us 4096 values for a full circle.
constexpr size_t sin_tables_bit_count = 12;

// Precompute the shift value to convert from angle units to sin table units.
constexpr size_t angle_to_sin_table_shift = angle_bit_count - sin_tables_bit_count;


// Inverse of the angle base so we can convert to floating point values without doing a division.
constexpr float angle_base_inverse = 1.0f / angle_base;


// Readout bit packing
// -------------------

constexpr size_t hall_state_bit_offset = 0;
constexpr uint8_t hall_state_bit_mask = 0b111 << hall_state_bit_offset;

constexpr size_t current_detected_bit_offset = 4;
constexpr uint8_t current_detected_bit_mask = 0b1 << current_detected_bit_offset;

constexpr size_t emf_fix_bit_offset = 5;
constexpr uint8_t emf_fix_bit_mask = 0b1 << emf_fix_bit_offset;

constexpr size_t emf_detected_bit_offset = 6;
constexpr uint8_t emf_detected_bit_mask = 0b1 << emf_detected_bit_offset;

// Position constants
// ------------------


// Gear ratio of our chosen motor.
constexpr float gear_ratio = 6.0 * 6.0 * 6.0;

// Total ratio between the electrical angle and the output shaft angle.
constexpr float ratio = rotor_revolutions_per_electric * gear_ratio;


// Electric constants
// ------------------


// Voltage reference for the ADC; it's the in-built reference on the STM32G4.
constexpr float adc_voltage_reference = 2.9f;

constexpr float amplifier_voltage_reference = 3.3f / 2;

// Shunt resistance for the motor phase current sensing is 10mOhm, 500mW resistor.
constexpr float current_shunt_resistance = 0.010f;

// The voltage on the shunt resistor is amplified by INA4181 Bidirectional, Low and 
// High Side Voltage Output, Current-Sense Amplifier.
constexpr float amplifier_gain = 20.0f;
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

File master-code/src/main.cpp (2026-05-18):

#include <stdio.h>

#include <functional>
#include <vector>

#include <freertos/FreeRTOS.h>
#include <freertos/task.h>

#include <freertos/message_buffer.h>
#include <esp_timer.h>
#include <nvs_flash.h>
#include <esp_task_wdt.h>
#include <esp_log.h>
#include <esp_err.h>

#include "display.hpp"
#include "io.hpp"
#include "wifi.hpp"
#include "https_server.hpp"
#include "utils.hpp"

#include "hex_mini_drive_interface.hpp"

static const char* TAG = "main";


using hex_mini_drive::SPI_TRANSACTION_SIZE;
using hex_mini_drive::MAX_MESSAGE_SIZE;

constexpr size_t max_buffer_size = 8 * 1024; // 8 KB buffer size for motor messages, adjust as needed


// Create an FreeRTOS byte stream buffer for data received from the motor to be sent via wifi.
MessageBuffer<max_buffer_size> received_from_motor;

// FreeRTOS message buffer for motor messages
MessageBuffer<max_buffer_size> sending_to_motor;


uint8_t zero_buffer[SPI_TRANSACTION_SIZE] = {0};

volatile bool wifi_is_connected = false;


const auto blink_status_led = interval(1000, []() {
  static bool status_state = false;

  status_state = !status_state;
  uint32_t duty = status_state ? 128 : 32;
  set_status_led_brightness(duty);
});


void wifi_connected(){
  ESP_LOGI(TAG, "Wi-Fi connected callback called");

  setup_server(/* core_id = */ 0, [](uint8_t* buffer, size_t size) {
    if (size > MAX_MESSAGE_SIZE) {
      ESP_LOGW(TAG, "Received message size %d exceeds maximum of %d, dropping message", size, MAX_MESSAGE_SIZE);
      return;
    }

    size_t sent = sending_to_motor.send(buffer, size);

    if (sent != size) {
      ESP_LOGW(TAG, "Failed to send full message to buffer (sent %d/%d bytes)", sent, size);
    }
  });

  wifi_is_connected = true;
}


// Our messages are 0 delimited, with extra 0s allowed. We want to compact them to a
// series of messages delimited by a single 0. We'll count these bytes as data received.
size_t compactify_data_buffer(uint8_t * buffer, size_t size) {
  // The first byte is correct even as a 0. Start pruning from the second byte.
  size_t write_index = 1;
  
  for (size_t read_index = 1; read_index < size; ++read_index) {
    if (buffer[read_index] != 0 or buffer[read_index - 1] != 0) {
      buffer[write_index++] = buffer[read_index];
    }
  }
  return write_index;
}

void motor_update(int64_t current_time_ms) {
  uint8_t write_buffer[SPI_TRANSACTION_SIZE] = {0};
  uint8_t read_buffer[SPI_TRANSACTION_SIZE] = {0};

  // Check if there's a message in the buffer
  if (not sending_to_motor.is_empty()) {
    const auto bytes_to_send = sending_to_motor.receive(write_buffer, MAX_MESSAGE_SIZE);
    if (bytes_to_send == 0) {
      ESP_LOGE(TAG, "Failed to receive message from buffer");
      return abort();
    }
  }

  // Run the spi transaction with motor data, or zeroes.
  motor_spi_transaction(0, write_buffer, read_buffer, SPI_TRANSACTION_SIZE);

  bool all_ff = true;
  for (size_t i = 0; i < SPI_TRANSACTION_SIZE; ++i) {
    if (read_buffer[i] != 0xFF) {
      all_ff = false;
      break;
    }
  }
  if (all_ff) {
    // Only bits of 1 is probably the line being held low at reset.
    return;
  }

  size_t read_size = compactify_data_buffer(read_buffer, SPI_TRANSACTION_SIZE);

  // Check if the message is bigger than a single 0.
  if (read_size <= 1) {
    return;
  }

  if (received_from_motor.available() < read_size) {
    received_from_motor.discarded += read_size;
    ESP_LOGW(TAG, "Discarded %d bytes from motor buffer due to insufficient space", read_size);
    return;
  }

  const size_t queued_size = received_from_motor.send(read_buffer, read_size);
  if (queued_size != read_size) {
    ESP_LOGE(TAG, "Failed to send full message to received_from_motor (sent less than %d bytes)", read_size);
    return abort();
  }
}

void core_0_task(void *arg) {
  // Register this task with the watchdog timer.
  esp_task_wdt_add(NULL);
  
  start_wifi_provisioning(wifi_connected);
  
  auto stats = RunningStats();

  auto log_loop_frequency = interval(5000, [&stats]() {
    ESP_LOGI(TAG, "Core 0 loop frequency: %.2f Hz", stats.loop_frequency);
  });

  while (1) {
    stats.update();

    // We need to reset the watchdog timer regularly.
    esp_task_wdt_reset();

    log_loop_frequency(stats.time_ms);

    if (wifi_is_connected) {
      update_server(stats.time_ms, [](uint8_t * buffer, size_t max_size) -> size_t {
        size_t total_to_send = 0;
        // This lambda is called by the server when it's ready to send data.
        while(total_to_send < max_size) {
          size_t bytes_received = received_from_motor.receive(buffer + total_to_send, max_size - total_to_send);
          if (bytes_received == 0) break;
          total_to_send += bytes_received;
        }
        return total_to_send;
      });
    }

    // Sleep for 1 ms.
    vTaskDelay(pdMS_TO_TICKS(1));
  }
}


void core_1_task(void *arg) {
  // Register this task with the watchdog timer.
  esp_task_wdt_add(NULL);

  // Setup everything
  setup_status_led();
  setup_spi_busses();
  setup_display_and_lvgl();

  update_display(get_ms_time());

  setup_output_pins();
  setup_shift_register_bank1();
  setup_shift_register_bank2();

  uint8_t bank2_defaults[7] = {
    0b0000'0000,
    0, 
    0, 
    0, 
    0, 
    0, 
    0b0000'0010, // Enable first motor by setting the reset pin high.
  };

  set_shift_register_bank2(bank2_defaults);

  uint8_t bank1_defaults[3] = {
    0xFF,
    0xFF, 
    0xFF, 
  };

  set_shift_register_bank1(bank1_defaults);

  enable_shift_register_outputs();

  // BIG oof, this burns the circuit, if the USB output flags are set wrong.
  connect_vbus_to_vcc();

  auto stats = RunningStats();

  auto log_loop_frequency = interval(10000, [&stats]() {
    ESP_LOGI(TAG, "Core 1 loop frequency: %.2f Hz", stats.loop_frequency);
  });

  while (1) {
    stats.update();

    // // We need to reset the watchdog timer regularly.
    esp_task_wdt_reset();
    
    // Blink the built-in status LED to show the system is running
    blink_status_led(stats.time_ms);

    // Handle displaya and LVGL tasks.
    update_display(stats.time_ms);

    log_loop_frequency(stats.time_ms);

    motor_update(stats.time_ms);

    // Sleep for 1ms.
    vTaskDelay(pdMS_TO_TICKS(1));
  }

  
}

extern "C" void app_main() {
  //Initialize NVS, used for WiFi provisioning and other settings.
  esp_err_t ret = nvs_flash_init();
  if (ret == ESP_ERR_NVS_NO_FREE_PAGES || ret == ESP_ERR_NVS_NEW_VERSION_FOUND) {
      ESP_ERROR_CHECK(nvs_flash_erase());
      ret = nvs_flash_init();
  }
  ESP_ERROR_CHECK(ret);

  // Start main task pinned to core 1 as core 0 is used by Wi-Fi and other system tasks.
  xTaskCreatePinnedToCore(core_1_task, "core_1_task", 16384 , NULL, 1, NULL, 1);
  xTaskCreatePinnedToCore(core_0_task, "core_0_task", 16384 , NULL, 1, NULL, 0);
}

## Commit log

2024-06-26 Tentatively complete the PCB layout.
    [hex-mini-drive.kicad_pcb, hex-mini-drive.kicad_sch]
2024-06-29 Finalise mini drive test circuit and generate production files.
    [bom.csv, designators.csv, hex-mini-drive.kicad_pcb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]
2024-07-09 Redo design with minimum 0.2mm line width and spacing.
    [bom.csv, designators.csv, hex-mini-drive.kicad_pcb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]
2024-07-16 Replan design with 2 sided IC components to make it more compact.
    [hex-mini-drive.kicad_pcb]
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2024-09-07 Correct channel configuration for current readouts.
    [hex-mini-drive.ioc]
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2024-09-19 Add 3D model of motor into the page with THREE.js; also a svg sketch.
    [motor_model.3mf]
2024-09-23 Ditch the SVG and stick to showing the 3D visuals.
    [motor_model.3mf]
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2024-10-08 Enable radial displacement so we simulate losses from misaligned emf.
    [simulation.js]
2024-10-09 Implement sounds! Fix the radial displacement physics to be in 2 dimensions. Dropoff magnetic flux linkage with displacement.
    [simulation.js]
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2024-10-14 Fix the simulation blowing up by avoiding to cross 0 in a single step.
    [simulation.js]
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2025-01-31 Send ADC readouts over USB, kinda error prone for now.
    [app_main.cpp, hex-mini-drive.ioc, interrupts.cpp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]
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2025-02-20 Shorten sampling time and sample when the motor leads are grounded each PWM cycle.
    [app_main.cpp, hex-mini-drive.ioc]
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2025-02-28 Refactor the USB code to read in a loop continuously.
    We need to read continuously in order to clear any messages that we might miss somehow. We also need to read faster than the frame update of 60hz so we don't pause reading for too long because the chip has very little memory.
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2025-03-01 Drop the floating state mode, it's wildly inefficient and causes a lot of ADC noise.
    [app_main.cpp, interrupts.cpp]
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2025-03-31 Calculate phase voltages correctly, overlay the voltage park angle with the hall sensors to prepare for calibration.
    [app_main.cpp, interrupts.cpp]
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2025-04-18 Shorten command to 16 bits, a standard usb packet only has 64 bits of data.
    [app_main.cpp, constants.hpp]
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2025-04-19 Reset the history buffer from the interrupt routine for perfect timing.
    [app_main.cpp, interrupts.cpp]
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2025-04-28 Rework the multiline plots to accept data via events.
    This bypasses the reactivity... but we need to in order to prevent the input buttons from flickering during animations.
2025-04-28 Fix download rate calculation.
    Add up data downloaded over 50 milliseconds to avoid dividing by 0 millis or rounding errors from time being in millis integers.
2025-04-29 Plot driver timing stats and fix hall timer handling.
    The hall timer update event was fired for both a trigger and an overflow, we have to switch our if statements around to test for a trigger first and clear both flags when that happens.
    [app_main.cpp, interrupts.cpp]
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2025-05-02 Fix linker warning.
    https://stackoverflow.com/questions/73429929/gnu-linker-elf-has-a-load-segment-with-rwx-permissions-embedded-arm-project
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2025-05-02 Add voltage and temperature to the injected ADC scan to avoid a 2nd interrupt.
    [constants.hpp, hex-mini-drive.ioc, interrupts.cpp]
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2025-05-15 Fix position calibration calculations.
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2025-05-18 Replace magic constant 2 with header_size.
    [motor_interface.js]
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2025-05-22 Fix current calibration stdev plotting.
    [motor_current_calibration.js]
2025-05-22 Fix EMF inference, really sweet readings now.
    [motor_interface.js]
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2025-05-23 Try to implement inductance calibration, not the right path.
    We took a shortcut when calibrating resistance by isolating the settling phases between voltage steps in the calibration data. Possibly a better way is multivariate regression; or we can just yolo sgd on it.
    [motor_current_calibration.js]
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2025-05-29 Revert floating point arithmetic, it was not good enough.
    This reverts commit 27c960ef38c099636fff34407c6ef1432c2b3ab7.
    [app_main.cpp, interface.cpp, interrupts.cpp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]
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2025-06-09 Drop the complicated speed via transition counting.
    We get much smoother speed estimates without it... also it simplifies the function a bunch and make sit 10% faster. Unfortunately we're stuck with large speed variance, maybe the EMF readings can help.
    [constants.hpp]
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2025-06-19 Fix PID limits and re-add target parameter.
    [interrupts.cpp]
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2025-06-23 Exponentially average the DQ0 calculations to reduce noise.
    [interrupts.cpp, motor_interface.js]
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2025-06-27 Directly correct the leading angle based on alpha_current.
    We need to compensate for the energy the rotor took from the coils while it could accelerate more easily than expected (when it gets bumped by the gear from behind).
    [constants.hpp, interface.cpp, interrupts.cpp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]
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2025-07-06 Implement constant speed fixed pwm drive mode.
    [app_main.cpp, constants.hpp, interface.cpp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]
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2025-07-10 Revert the sin table refinement, it greatly slowed down the loop.
    [constants.hpp]
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2025-07-14 Fix periodic mode duration countdown.
    [interrupts.cpp]
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2025-07-15 Drop the current cancelling, doesn't seem to make a big difference.
    [interrupts.cpp]
2025-07-15 Smooth out PWM commands, seems to fix a lot of issues.
    [constants.hpp, interface.cpp, interrupts.cpp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]
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2025-07-18 Remove PID parameters; integrate into control parameters.
    We dropped the uniform parameter structs in favour of a single big parameter struct with all the variables, with different possible meanings (maximums or integral gains). We also drop the pid calculation in favour of simple integral controllers because the cycle frequency is high enough that we always want to average out the noise over a few cycles. Thus the proportional and derivative terms are too noisy for meaningful control, but at 23khz the integral only control converges very quickly so we don't need the extra terms. This lets us free up some compute and reduce a piece of mutable state.
    [app_main.cpp, constants.hpp, interface.cpp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]
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2025-07-21 Adjust the angle fixing algo.
    [constants.hpp, interrupts.cpp, motor_interface.js]
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2025-07-25 Fix current calibration setup.
    [motor_current_calibration.js]
2025-07-25 Flip the rotor angle at the start of the cycle to use a consistent angle in DQ0 frame.
    [interrupts.cpp]
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2025-07-25 Adjust the duty and diff calculations. Averaging over 2 timesteps lowers noise significantly.
    [interrupts.cpp]
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2025-07-26 Fix the direction flipping (finally, finally)!
    [constants.hpp, interface.cpp, interrupts.cpp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]
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2025-07-27 Fix torque control! Increase the accumulator resolution and only divide for the output.
    [constants.hpp, interrupts.cpp]
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2025-07-28 Count the number of rotations and fix torque mode.
    [constants.hpp, interface.cpp, interrupts.cpp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]
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2025-07-31 Fix current magnitude calculation and drop the ceil divisions.
    [constants.hpp, interface.cpp, interrupts.cpp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]
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2025-08-01 Fix the sign of the torque control.
    [constants.hpp, interrupts.cpp]
2025-08-01 Simplify the emf fix logic.
    [interrupts.cpp]
2025-08-01 Re-add the hall angle so we always have an angle fix.
    [constants.hpp, interface.cpp, interrupts.cpp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]
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2025-08-02 Remove error calls from the interrupts!
    [interrupts.cpp]
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2025-08-06 Fix the PWM limiting logic.
    [constants.hpp, interrupts.cpp]
2025-08-06 Rename alpha and beta to direct and quadrature because we skipped the Clarke transform.
    [constants.hpp, interface.cpp, interrupts.cpp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]
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2025-08-18 Add parameter to flip rotation direction, move motor constant to main loop.
    [app_main.cpp, constants.hpp, interface.cpp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]
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2025-10-06 Begin new circuit design.
    [hex-minidrive.kicad_pcb, hex-minidrive.kicad_sch]
2025-10-10 Tentatively finish new schematic.
    [hex-minidrive.kicad_pcb, hex-minidrive.kicad_sch]
2025-10-13 Finish the new version schematic.
    [hex-minidrive.kicad_pcb, hex-minidrive.kicad_sch]
2025-10-14 Update electrical design rules.
    [hex-minidrive.kicad_pcb, hex-minidrive.kicad_sch]
2025-10-20 Near final v0.2 circuit design.
    [hex-minidrive.kicad_pcb, hex-minidrive.kicad_sch]
2025-10-21 Add a logo and finish circuit.
    [Hex logo.dxf, hex-minidrive.kicad_pcb]
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2025-10-22 Copy v0.2 to v0.3 to work on USB PD.
    [bom.csv, designators.csv, hex-minidrive.kicad_pcb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]
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2025-11-10 Plugin rotation sensor for servos.
    [Rotation sensor outline.dxf, sensor-circuit.kicad_pcb, sensor-circuit.kicad_sch]
2025-11-10 Update schematic information panel.
    [hex-mini-drive.kicad_sch, hex-minidrive.kicad_sch]
2025-11-10 Make schematic for master circuit to control multiple servos.
    [master-circuit.kicad_pcb, master-circuit.kicad_sch]
2025-11-10 Sketch out v0.3 of the servo driver, without the USB port.
    [hex-minidrive.kicad_pcb, hex-minidrive.kicad_sch]
2025-11-12 Finish master controller circuit, arrange chips on the board.
    [back-to-back-mosfets.kicad_sch, group-of-8-servo-connectors.kicad_sch, master-circuit.kicad_pcb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]
2025-11-13 Partially wire up control circuit.
    [master-circuit.kicad_pcb, master-circuit.kicad_sch]
2025-11-14 Continue wiring control circuit.
    [master-circuit.kicad_pcb, master-circuit.kicad_sch]
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2025-11-18 Complete wiring up control circuit (needs verifying).
    [master-circuit.kicad_sch]
2025-11-18 Finish the control circuit layout.
    [Hex logo midline.dxf, sensor-circuit.kicad_pcb]
2025-11-20 Prepare the master circuit for manufacturing (fixed component placement and orientation).
    [bom.csv, designators.csv, positions.csv]
2025-11-21 Fix sensors panel for production.
    [bom.csv, designators.csv, positions.csv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]
2025-11-24 Correction for sensor circuit.
    [sensor-circuit.kicad_pcb]
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2025-12-02 Copy driver code and modify until it compiles (wrong pinout!).
    [app_main.cpp, constants.hpp, interface.cpp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]
2025-12-03 Adapt code for new STM32, but we have the wrong chip selected in the CubeMX!
    [app_main.cpp, hex-mini-drive.ioc, interrupts.cpp]
2025-12-03 Switch to the correct chip version.
    [hex-mini-drive.ioc]
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2025-12-18 Fix off by 1 errors.
    [interrupts.cpp]
2025-12-18 Replace the buffer stuff with a flag.
    [interrupts.cpp]
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2025-12-20 Fix the stop button.
    [app_main.cpp, io.hpp]
2025-12-22 Think about v0.3 driver circuit.
    [hex-minidrive.kicad_pcb, hex-minidrive.kicad_sch]
2025-12-22 Move USB timeout logic into app_main code, fix write buffering.
    [app_main.cpp]
2025-12-27 Start re-wiring v0.3 motor driver, 16mm width is too tight.
    [hex-minidrive.kicad_pcb, hex-minidrive.kicad_sch]
2025-12-29 Sketch out route for all crossing wires.
    [hex-minidrive.kicad_pcb]
2025-12-29 Almost done wiring, but paths need refining.
    [hex-minidrive.kicad_pcb]
2025-12-30 More circuit progress, there are ground islands, hmm.
    [hex-minidrive.kicad_pcb]
2026-01-02 Optimized routing, but we need to go tighter.
    [hex-minidrive.kicad_pcb]
2026-01-02 Thinned out the signal lines and tightened the layout, now to fit power caps.
    [hex-minidrive.kicad_pcb]
2026-01-02 Finished v0.3 circuit layout.
    [hex-minidrive.kicad_pcb, hex-minidrive.kicad_sch]
2026-01-03 Fix positioning errors and realize SPI3 is not in the bootloader options.
    [bom.csv, hex-minidrive.kicad_pcb, hex-minidrive.kicad_sch]
2026-01-03 Sigh, SPI3 cannot be used for the bootloader, move to SPI2. Finish v0.3 again.
    [hex-minidrive.kicad_pcb, hex-minidrive.kicad_sch]
2026-01-04 Finalize v0.3 and generate production files.
    [designators.csv, hex-minidrive.kicad_pcb, positions.csv]
2026-01-08 Compile and test master circuit for liveness. It lives!
    [master-circuit.kicad_sch]
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2026-01-19 Add custom partitions table and use max CPU frequency.
    [partitions.csv]
2026-01-19 Implement wifi with qrcode provisioning. Doesn't work tho...
    [main.cpp]
2026-01-20 Fix the watchdog timer issue.
    [display.cpp, main.cpp]
2026-01-20 Enlarge the spiffs partition so we can load the whole web page.
    [partitions.csv]
2026-01-23 Name the v0.1 circuit with the version tag.
    [bom.csv, designators.csv, hex-mini-drive.kicad_pcb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]
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2026-04-08 Fix SPI comms for this circuit, we used the same spi line to also set the chip select pin...
    So we actually need to send the last 3 bytes to deassert all chip select lines.
    [io.cpp]
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2026-04-13 Fix the ESP IDF version and make it work from the dockerfile.
    [main.cpp]
2026-04-16 Fully reset the encoder buffers.
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2026-05-29 Fix some js serialization errors.
    [interface.js]
2026-05-29 Make driver v0.3 the main code and replace driver-code-v0.2.
    [app_main.cpp, constants.hpp, hex-mini-drive.ioc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]
2026-05-29 Copy v0.3 as starting point for v0.4
    [hex-minidrive.kicad_pcb, hex-minidrive.kicad_sch]
2026-05-29 Convert to kicad 10.
    [hex-minidrive.kicad_pcb, hex-minidrive.kicad_sch]
2026-05-29 Fix LED pwm setting, now green light works.
    [hex-mini-drive.ioc]
2026-05-29 Begin the v0.4 driver code.
    [hex-minidrive.kicad_sch]
2026-06-01 Make schematic for v0.4 driver circuit.
    [hex-minidrive.kicad_pcb, hex-minidrive.kicad_sch]
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2026-06-03 Finish and generate production files for v0.4 driver circuit.
    [bom.csv, designators.csv, hex-minidrive.kicad_pcb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]
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2026-06-17 Drop unused features and arrange components on new master circuit board.
    [back-to-back-mosfets.kicad_sch, master-circuit.kicad_pcb, master-circuit.kicad_sch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]
2026-06-18 Connect one of the USB outputs, outline part placement.
    [back-to-back-mosfets.kicad_sch, master-circuit.kicad_pcb, master-circuit.kicad_sch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]
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2026-06-19 Deal with most of the connection spider web, connector lines remaining.
    [master-circuit.kicad_pcb, master-circuit.kicad_sch]
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2026-06-23 Make schematic for the cable plug and extension circuit.
    [extender-cable-circuit.kicad_pcb, extender-cable-circuit.kicad_sch, master-circuit.kicad_sch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]
2026-06-26 Working on rally compact layout for cable extender.
    [extender-cable-circuit.kicad_pcb, extender-cable-circuit.kicad_sch, servo-usb-connector.kicad_sch]
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2026-06-29 Work on cable outline, and almost finish wiring.
    [Cable circuit outline.dxf, extender-cable-circuit.kicad_pcb, extender-cable-circuit.kicad_sch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]
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2026-07-03 Argh, some chips out of stock, got to do a slight redesign.
    [back-to-back-mosfets.kicad_sch, bom.csv, designators.csv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]
2026-07-03 Export the stiffener layer too, duh...
    [extender-cable-circuit.kicad_pcb]
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2026-07-06 Fix transmitting pwm values with the higher pwm base.
    [interface.js, interrupts.cpp]
2026-07-07 Fix timing issue so we measure phases at mid PWM cycle.
    [constants.hpp, hex-mini-drive.ioc, io.hpp]
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2026-07-08 Fix ADC2 readings, we were only reading 1 value and masking the result by adjusting the sum to 0.
    [hex-mini-drive.ioc, interrupts.cpp, io.hpp]
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2026-07-10 Fix drive smooth command to have int pwm parameter.
    [constants.hpp]
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2026-07-20 Concentrate bound checks in a single location, fix max power bug.
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2026-07-23 Remove the rotor correction code for now.
    [interrupts.cpp]
2026-07-23 Fix shared history handling via a reset flag.
    [interrupts.cpp]
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2026-07-24 Only reset history with new driver state.
    [interrupts.cpp]
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2026-08-18 Fix the emf detection logic.
    [constants.hpp, interface.js, interrupts.cpp]
2026-08-18 Fix smooth driving with a small parameter tweak.
    [constants.hpp]
2026-08-19 Don't compensate for EMF in the smooth mode, it's glitchy and costly in compute.
    [constants.hpp, interrupts.cpp]
2026-08-19 Fix the current detection threshold.
    [constants.hpp, interrupts.cpp]
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2026-08-20 We didn't need to cast to int anymore.
    [app_main.cpp]
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2026-08-25 Add flags for nominal vcc voltage, over power draw and too much resistive heating.
    [constants.hpp, interface.js, interrupts.cpp]
2026-08-25 Revert back to resilient gradient descent because its more resilient to init learning rates.
    [constants.hpp]
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2026-08-27 Move the max pwm update to the main loop, this saves us 110 ticks in the tight loop.
    [app_main.cpp, interrupts.cpp]
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2026-09-01 Wow, when correctly adjusted to idle at 0, the motor is really sensitive to emf now. Sensorless nearly achieved!
    [app_main.cpp, constants.hpp, interface.js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]
2026-09-01 Fix phase resistance calibration and check if inductance also varies with rotor angle.
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2026-09-02 Move current calibration back into the monitor, it's tightly integrated.
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2026-09-07 Switch from the EMF calibration to a chirp at a fixed angle with oscillating amplitude.
    [app_main.cpp, interrupts.cpp]
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2026-09-07 We can fix the dead time of the bridges by turning all phases on for a minimum fraction.
    [constants.hpp, interrupts.cpp]
2026-09-08 Calibrate the motor constant with a short spinup routine before the calibration.
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2026-09-09 Fix sign of the velocity component, maybe...
2026-09-09 Heyo, it wasn't the minimum pwm that was a problem, it looks like the W phase turns on faster than U and V, need to adjust for that soon.
    [interrupts.cpp, io.hpp]
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2026-09-10 Flip our signs for the saliency angle calibration to match our rotor position definition.
2026-09-11 Implement a broken position tracking by optimizing every rotor angle along a trajectory.
2026-09-11 Fix the angle adjustment to the previous dq0 frame.
    [interrupts.cpp]
2026-09-12 Reuse the lead angle to smooth out transition between position fix and no fix.
    [interrupts.cpp]
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2026-09-24 Recalculate emf_power and total_power using the lower noise estimates.
    [interrupts.cpp]
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2026-09-24 Oopsie, fix gradient of base inductance. We need to optimize independently of the inductance bias contribution.
    [constants.hpp, interrupts.cpp]
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2026-09-28 Remove the variance correction, not effective enough.
    [interrupts.cpp]
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2026-09-29 Fix the torque current calculation.
    [interrupts.cpp]
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2026-10-21 We need to avoid calibrating during emf time!
2026-10-22 Fix emf detection logic, now calibration is a lot more stable.
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2026-10-24 Calculate the correlation between emf speed and drive voltage speed, it's consistently high during glitchy behaviour.
2026-10-28 Add the EMF back into the resistance calibration, but oh no... it's still broken.
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2026-11-05 Reduce extra calibration state and add stability condition so we can scan faster.
2026-11-05 Flip saliency angle in case we go negative.
